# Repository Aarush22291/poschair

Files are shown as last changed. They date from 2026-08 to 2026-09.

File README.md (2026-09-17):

# 🪑 PosChair v1.3 — AI-Powered Active Posture Correction Chair
### Master Technical & Operating Manual

> **Patent Pending · PosChair Technologies Inc.**  
> An active posture correction system powered by real-time computer vision, biomechanical kinematic modeling, and a 6-zone motorized paraspinal backrest attachment.






> **Current readiness:** The software is hardened for prototype evaluation. The powered chair remains an **unoccupied bench prototype** until the [production-readiness hardware gates](docs/production_readiness.md) are completed and independently verified.

---

## 📋 Table of Contents

1. [Executive Summary & Biomechanical Concept](#-1-executive-summary--biomechanical-concept)
2. [How to Run PosChair in 60 Seconds (Beginner Guide)](#-2-how-to-run-poschair-in-60-seconds-beginner-guide)
3. [Full Application Dashboard & UI Guide](#-3-full-application-dashboard--ui-guide)
4. [Biomechanical Kinematics & Math Formulas](#-4-biomechanical-kinematics--math-formulas)
5. [2×3 Paraspinal Actuator Matrix Architecture](#-5-23-paraspinal-actuator-matrix-architecture)
6. [Hardware Wiring & Assembly Reference](#-6-hardware-wiring--assembly-reference)
7. [NimBLE Bluetooth Low Energy Protocol (v1.3)](#-7-nimble-bluetooth-low-energy-protocol-v13)
8. [Software Development & Build Commands](#-8-software-development--build-commands)
9. [Complete Repository Directory Map](#-9-complete-repository-directory-map)
10. [Troubleshooting & Frequently Asked Questions (FAQ)](#-10-troubleshooting--frequently-asked-questions-faq)
11. [Safety & Watchdog Failsafe Systems](#-11-safety--watchdog-failsafe-systems)
12. [Patent Reservation & License Notice](#-12-patent-reservation--license-notice)

---

## 💡 1. Executive Summary & Biomechanical Concept

### The Problem with Ergonomic Chairs
Traditional ergonomic office chairs are **passive support structures**. They only assist your lumbar spine if you maintain ideal posture voluntarily. As fatigue sets in during desk work, users inevitably slump forward (thoracic kyphosis), lean to one side (asymmetric spinal loading), or crane their neck toward the monitor ("tech neck"). Passive chairs do nothing to detect or correct these biomechanical failures.

### The PosChair Active Solution
PosChair is a **vision-guided ergonomic chair prototype**:
* **Camera Vision Eye:** Tracks 33 3D body landmarks using MediaPipe Pose executing inside client-side WebAssembly (WASM). No video or coordinate data is uploaded by the vision pipeline.
* **Kinematic Posture Engine:** Calculates spine forward deviation, lateral roll tilt, and neck inclination angle relative to a personalized 5-second baseline pose.
* **Motorized Actuation Matrix:** A 2×3 grid of 6 motorized worm-rack actuators provides up to **55mm** of configured prototype travel. Occupied operation requires the independent limits, force controls, and emergency stop listed in the hardware safety gate.

```text
+-----------------------------------------------------------------------------------+
|                           POSCHAIR VISION-GUIDED PROTOTYPE                        |
|                                                                                   |
|  [ User sitting ] ---> [ Browser Webcam ] ---> [ MediaPipe Pose WASM (33 Points) ]|
|          ^                                                   |                    |
|          |                                                   v                    |
|  [ 2x3 Motor Support ] <--- [ ESP32 & H-Bridges ] <--- [ NimBLE BLE (8 Bytes) ]   |
+-----------------------------------------------------------------------------------+
```

---

## ⚡ 2. How to Run PosChair in 60 Seconds (Beginner Guide)

You can run PosChair **with or without physical hardware connected**. If you don't have the hardware built yet, PosChair includes a **Live Hardware Simulator** directly on the camera screen so you can test all posture features immediately!

### System Requirements
* **Operating System:** Windows 10/11, macOS, or Linux.
* **Browser:** **Google Chrome** or **Microsoft Edge** (Required for Web Bluetooth API). Safari and Firefox do NOT support Web Bluetooth.
* **Webcam:** Any standard USB or built-in webcam ($640 \times 480$ or higher).
* **Node.js:** Node.js **24.x LTS** (pinned in CI).
* **Python:** Python **3.12.x** (pinned in CI for backend checks).

---

### Method A: Double-Click Desktop Launcher (Easiest — No Code Required)

1. Download or clone this repository to your computer.
2. Open the project folder in Windows Explorer.
3. Double-click the file:
   ```text
   run-poschair.bat
   ```
4. The launcher will install missing packages automatically, start the server, and open **`http://localhost:5173`** in your default web browser!

---

### Method B: Manual Command Line Launch

Open Terminal or Command Prompt in the repository folder:

```bash
# 1. Enter the frontend application directory
cd app/frontend

# 2. Install dependencies (only required on first run)
npm install

# 3. Launch the development server
npm run dev
```

Open **`http://localhost:5173`** in Google Chrome or Microsoft Edge.

---

### Method C: Full-Stack Docker Container Launch

For developers running the full backend stack (React Frontend + FastAPI Backend + PostgreSQL Database):

```bash
cd app
docker-compose up --build
```

Open **`http://localhost:5173`** in Chrome or Edge.

---

## 🎮 3. Full Application Dashboard & UI Guide

When you open the application at `http://localhost:5173`, the dashboard provides real-time biomechanical feedback:

```text
+----------------------------------------------------------------------------------+
|  POSCHAIR v1.3               [ Connect Chair ]  [ Stop Camera ]  [ Mode: Office ]|
+----------------------------------------------------------------------------------+
|                                        |                                         |
|   LIVE POSTURE VIDEO FEED              |   CHAIR HARDWARE VISUALIZER             |
|   +--------------------------------+   |   +---------------------------------+   |
|   | [Score: 85 (Good)]  [HARDWARE] |   |   |  Upper-Left:  18mm  [====---]  |   |
|   |                     [DIAGRAM ] |   |   |  Upper-Right: 18mm  [====---]  |   |
|   |   (33 Yellow Joint Dots &      |   |   |  Mid-Left:    45mm  [========]  |   |
|   |    Green/Red Spine Line)       |   |   |  Mid-Right:   45mm  [========]  |   |
|   |                                |   |   |  Lower-Left:  32mm  [======--]  |   |
|   | [Spine:+8.4°] [Lat:-1.2°]      |   |   |  Lower-Right: 32mm  [======--]  |   |
|   +--------------------------------+   |   +---------------------------------+   |
|                                        |                                         |
|   [ Calibrate Baseline ] [ Session Clock ] |   INTEGRATION SETTINGS                  |
|   Spine Velocity: +2.1 deg/s           |   [ Local CV Only ]  [ Active BLE Loop ] |
|                                        |                                         |
|   ANALYTICS TREND CHART                |   MANUAL POSITION OVERRIDE              |
|   [==================================] |   Module 1 Position: [-------o----] 35mm|
+----------------------------------------------------------------------------------+
```

### Detailed Feature Breakdown

#### 1. Live Posture Video Panel (`CameraView.tsx`)
* **Full Body Skeleton Overlay:** Draws all 33 pose landmarks as prominent **yellow dots** (matching the physical reference design).
* **Posture-Aware Spine Line:** Highlights the line from Hip Midpoint → Shoulder Midpoint → Ear Midpoint:
  * **Green:** Excellent alignment ($\text{Score} \ge 75$)
  * **Yellow/Amber:** Minor posture deviation ($\text{Score } 50\text{--}74$)
  * **Red:** Severe posture slump ($\text{Score} < 50$)
* **Live Bottom Metric Pills:**
  * **`Spine (°)`:** Angle of torso forward lean relative to vertical (e.g. `+12.4°`).
  * **`Lateral (°)`:** Shoulder roll tilt angle left/right (e.g. `-4.2°`).
  * **`Neck (°)`:** Ear-to-shoulder inclination angle (Tech Neck proxy, e.g. `+14.7°`).
  * **`Confidence (%)`:** Pose tracking confidence score (e.g. `98% conf`).

#### 2. Live Hardware Motor Simulator Widget (Top-Right of Video)
* **Vibrant Blue Oval Chair Backrest Diagram (`front side of chair`):** Represents the physical backrest layout.
* **6 Actuator Nodes (`UL`, `UR`, `ML`, `MR`, `LL`, `LR`):**
  * **Bright Yellow (`0mm`):** Motor is idle/resting.
  * **Glowing Red + Pulse (`1–55mm`):** The prototype is commanding actuator extension.
  * **Real-time Readout:** Displays exact millimeter extension inside each circle.

#### 3. 5-Second Baseline Calibration (`CalibrationModal.tsx`)
* Clicking **"Calibrate Baseline"** prompts you to sit in your natural, healthy upright pose for 5 seconds.
* The system samples high-confidence frames ($\text{confidence} \ge 0.65$) and calculates your personalized baseline values:
  * $\text{spineAngle0}$, $\text{lateralAngle0}$, $\text{neckAngle0}$, $\text{shoulderWidth}$, $\text{torsoLength}$.
* All posture deviations are measured **relative to your baseline**, ensuring accurate operation regardless of camera height or user body dimensions.

#### 4. Posture Modes (`ModeSelector.tsx`)
* **Office Mode ($1.0\times$):** Standard balanced posture correction.
* **Gaming Mode ($1.2\times$):** Higher aggressiveness for forward-slouched gaming sessions.
* **Study Mode ($0.85\times$):** Moderated support for reading/writing.
* **Relax Mode ($0.5\times$):** Gentle baseline support.

#### 5. Integration Settings
* **Local CV Only:** Runs full camera tracking, biomechanical analysis, and live UI motor simulation without transmitting Bluetooth packets.
* **Active BLE Loop:** Continuously streams 8-byte command packets to the physical ESP32 chair controller over Bluetooth.

---

## 🧮 4. Biomechanical Kinematics & Math Formulas

### 1. Scale & Distance Invariance
To ensure posture calculations remain identical whether you sit close to or far from your webcam, all vector distances are scaled by your baseline **Torso Length** and **Shoulder Width**:

$$\text{torsoScale} = \frac{\text{CurrentTorsoLength}}{\text{BaselineTorsoLength}}$$

$$\text{forwardHeadRatio} = \frac{\text{MidEar}_x - \text{MidShoulder}_x}{\text{ShoulderWidth} \times \text{torsoScale}}$$

### 2. Exponential Moving Average (EMA) Temporal Filter
To eliminate camera frame jitter while retaining real-time responsiveness, all raw angular outputs pass through an EMA filter ($\alpha = 0.35$):

$$S_t = \alpha \cdot X_t + (1 - \alpha) \cdot S_{t-1}$$

### 3. Neck Inclination Angle (Tech Neck Proxy)
Calculated using the ear-to-shoulder inclination vector averaged across left and right sides:

$$\theta_{\text{neck}} = \text{atan2}(|\text{Ear}_x - \text{Shoulder}_x|, |\text{Ear}_y - \text{Shoulder}_y|) \times \left(\frac{180}{\pi}\right)$$

### 4. 3-Component Posture Score Formula
$$\text{Score} = \max\left(0, \min\left(100, 100 - P_{\text{spine}} - P_{\text{lateral}} - P_{\text{neck}}\right)\right)$$

Where:
* $P_{\text{spine}} = \min\left(40, \frac{|\Delta \text{Spine}|}{20^\circ} \times 40\right)$
* $P_{\text{lateral}} = \min\left(30, \frac{|\Delta \text{Lateral}|}{10^\circ} \times 30\right)$
* $P_{\text{neck}} = \min\left(30, \frac{|\Delta \text{Neck}|}{25^\circ} \times 30\right)$

### 5. Velocity Bonus & Differential Lateral Split
* **Velocity Bonus:** Adds up to $+15\text{mm}$ extra motor extension if the user slumps rapidly ($\text{SpineVelocity} > 3^\circ/\text{s}$).
* **Differential Lateral Split:**
  * Leaning **RIGHT** ($\Delta \text{Lateral} > +2^\circ$) $\rightarrow$ Adds extension bonus exclusively to **Right Column** (`UR`, `MR`, `LR`).
  * Leaning **LEFT** ($\Delta \text{Lateral} < -2^\circ$) $\rightarrow$ Adds extension bonus exclusively to **Left Column** (`UL`, `ML`, `LL`).

---

## 🪑 5. 2×3 Paraspinal Actuator Matrix Architecture

The physical chair attachment features 6 worm-rack actuators arranged in a **2×3 grid**:

```text
        LEFT COLUMN          RIGHT COLUMN
ROW 1:  [ M0 - UL ]         [ M1 - UR ]      Upper Thoracic / Shoulder
ROW 2:  [ M2 - ML ]         [ M3 - MR ]      Mid Lumbar
ROW 3:  [ M4 - LL ]         [ M5 - LR ]      Lower Lumbar / Pelvis
```

* **Center Spinal Channel:** A 2cm open vertical gap down the center ensures pads press into the **paraspinal muscle lines**, never pressing directly on spinal vertebrae.
* **Flex Strips:** Actuators drive pre-curved **65Mn spring steel strips** that provide 20mm of natural curvature at rest and flex up to 55mm total extension under load.

---

## 🔌 6. Hardware Wiring & Assembly Reference

### Bill of Materials (BOM)
| Item | Qty | Description / Part Notes |
|---|---:|---|
| **ESP32 DevKit V1** | 1 | 38-pin microcontroller (`ESP32 Dev Module`) |
| **BTS7960 Motor Driver** | 6 | High-current H-Bridge drivers (1 per motor) |
| **DC Geared Motors** | 6 | High-torque 12V DC geared motors with worm-racks |
| **12V Motor Battery/Power**| 1 | Dedicated 12V 10A+ motor power supply |
| **120kΩ Resistor** | 1 | Battery divider high-side resistor |
| **27kΩ Resistor** | 1 | Battery divider low-side resistor |
| **100nF Capacitor** | 1 | ADC midpoint filtering capacitor |
| **Inline Fuse** | 1 | Sized for the motor supply and wiring |
| **Latching Emergency Stop** | 1 | Required before any occupied-chair testing |
| **Common Ground Bus** | 1 | Required common ground line |

---

### ESP32 Pin Connection Table

| Module Index | Body Position | BTS7960 RPWM | BTS7960 LPWM | Shared Enable | Motor Output |
|---|---|---|---|---|---|
| **M0** | Upper-Left (UL) | ESP32 `GPIO25` | ESP32 `GPIO26` | `GPIO5` | Motor 0 `M+`/`M-` |
| **M1** | Upper-Right (UR) | ESP32 `GPIO27` | ESP32 `GPIO16` | `GPIO5` | Motor 1 `M+`/`M-` |
| **M2** | Mid-Left (ML) | ESP32 `GPIO14` | ESP32 `GPIO13` | `GPIO5` | Motor 2 `M+`/`M-` |
| **M3** | Mid-Right (MR) | ESP32 `GPIO17` | ESP32 `GPIO18` | `GPIO5` | Motor 3 `M+`/`M-` |
| **M4** | Lower-Left (LL) | ESP32 `GPIO21` | ESP32 `GPIO22` | `GPIO5` | Motor 4 `M+`/`M-` |
| **M5** | Lower-Right (LR) | ESP32 `GPIO23` | ESP32 `GPIO19` | `GPIO5` | Motor 5 `M+`/`M-` |

---

### BTS7960 Driver Connections (Per Driver Board)

```text
  +--------------------------------------------------------------------+
  |                        BTS7960 H-BRIDGE DRIVER                     |
  |                                                                    |
  |   RPWM ----> Assigned ESP32 RPWM GPIO (Extends motor)             |
  |   LPWM ----> Assigned ESP32 LPWM GPIO (Retracts motor)            |
  |   R_EN ----> ESP32 GPIO5 (Shared Driver Enable)                   |
  |   L_EN ----> ESP32 GPIO5 (Shared Driver Enable)                   |
  |   VCC  ----> ESP32 3.3V (Logic Power)                             |
  |   GND  ----> Common Ground Bus                                    |
  |   B+   ----> 12V Motor Battery Positive                           |
  |   B-   ----> Common Ground Bus (12V Battery Negative)             |
  |   M+   ----> DC Geared Motor Terminal 1                           |
  |   M-   ----> DC Geared Motor Terminal 2                           |
  +--------------------------------------------------------------------+
```

> ⚡ **CRITICAL POWER RULES:**  
> 1. **Common Ground:** ESP32 GND, BTS7960 GND, and 12V Battery Negative MUST be connected to a single common ground bus.  
> 2. **Separate Motor Rail:** Never power DC motors directly from the ESP32 board or USB cable.  
> 3. **Motor Polarity:** If a motor retracts when it should extend, swap its `M+` and `M-` wires on the BTS7960 driver terminal.

---

### Battery Voltage Sensing Circuit
Use a 120kΩ/27kΩ divider to keep the ESP32 ADC input below 3.3V throughout the supported 0-15V motor-supply range. Add a 100nF capacitor from the ADC midpoint to ground:

```text
12V Battery Positive ---- [ 120kΩ R1 ] ----+---- [ 27kΩ R2 ] ---- Ground Bus
                                            |
                                      ESP32 GPIO34
                                            |
                                         [100nF]
                                            |
                                      Ground Bus
```

> **Do not use the former 100kΩ/100kΩ divider.** A 12V input would place about 6V at the midpoint, above the ESP32 ADC pin limit and capable of damaging the controller.

---

## 📡 7. NimBLE Bluetooth Low Energy Protocol (v1.3)

* **Device Local Name:** `POSCHAIR_001`
* **Service UUID:** `a1b2c3d4-0001-4b5c-8d6e-1f2a3b4c5d6e`
* **Command Characteristic:** `a1b2c3d4-0002-4b5c-8d6e-1f2a3b4c5d6e` (Write Without Response)
* **Status Characteristic:** `a1b2c3d4-0003-4b5c-8d6e-1f2a3b4c5d6e` (Notify)

### 8-Byte Command Packet Map (App → ESP32)

| Byte | Field | Type | Value Range | Description |
|---|---|---|---|---|
| `0` | Header | `uint8_t` | `0xA5` | Fixed packet start byte |
| `1` | UL Position | `uint8_t` | `0–55` | Target extension in millimeters |
| `2` | UR Position | `uint8_t` | `0–55` | Target extension in millimeters |
| `3` | ML Position | `uint8_t` | `0–55` | Target extension in millimeters |
| `4` | MR Position | `uint8_t` | `0–55` | Target extension in millimeters |
| `5` | LL Position | `uint8_t` | `0–55` | Target extension in millimeters |
| `6` | LR Position | `uint8_t` | `0–55` | Target extension in millimeters |
| `7` | Checksum | `uint8_t` | Byte | XOR verification of bytes 0–6 |

$$\text{Checksum} = B_0 \oplus B_1 \oplus B_2 \oplus B_3 \oplus B_4 \oplus B_5 \oplus B_6$$

### Command Packet Debug Vectors

```text
All Motors Home (0mm):           A5 00 00 00 00 00 00 A5
Mid Lumbar Actuation (32mm):     A5 00 00 20 20 00 00 A5
Right Column Full Out (55mm):    A5 00 37 00 37 00 37 92
Full Matrix Out (55mm):          A5 37 37 37 37 37 37 A5
```

---

## 8. Software Development & Build Commands

### Frontend Development (React + Vite + TypeScript)
```bash
cd app/frontend
npm install
npm run dev      # Start Vite dev server on http://localhost:5173
npm run lint     # ESLint quality gate (0 warnings allowed)
npm run test     # Vitest unit tests
npm run build    # Production build check (tsc && vite build)
```

### Marketing Website Development (Next.js)
```bash
cd website
npm install
npm run dev      # Start Next.js dev server on http://localhost:3000
npm run lint     # ESLint quality gate (0 warnings allowed)
npm run build    # Production static page build (next build)
```

### Backend Development (FastAPI + SQLAlchemy)
```bash
cd app/backend
python -m pip install -r requirements-dev.txt
python -m ruff check src tests
python -m ruff format --check tests
DATABASE_URL=sqlite:///./test_poschair.db python -m pytest -q
```

### Developer Quick-Check (Pre-PR)
```bash
# Frontend
cd /home/runner/work/poschair/poschair/app/frontend && npm run lint && npm run test && npm run build

# Website
cd /home/runner/work/poschair/poschair/website && npm run lint && npm run build

# Backend
cd /home/runner/work/poschair/poschair/app/backend && python -m ruff check src tests && python -m ruff format --check tests && DATABASE_URL=sqlite:///./test_poschair.db python -m pytest -q
```

### Firmware Compilation (Arduino IDE 2.x)
1. Open `firmware/poschair_firmware/poschair_firmware.ino` in Arduino IDE.
2. Install Library: **NimBLE-Arduino** (via Library Manager).
3. Board Selection: **`ESP32 Dev Module`**.
4. Settings: CPU Frequency `240MHz`, Flash Size `4MB`.
5. Upload Speed: `921600`.

---

## 📁 9. Complete Repository Directory Map

```text
poschair_final/
├── run-poschair.bat            # 1-Click Desktop Launcher for Windows
├── README.md                   # Master Technical & Operating Manual
├── LICENSE                     # Proprietary & Patent-Pending License
├── app/
│   ├── frontend/               # Dashboard App (React, Vite, Web Bluetooth, MediaPipe)
│   │   ├── src/
│   │   │   ├── App.tsx         # Core App component, state management, retry loader
│   │   │   ├── poseDetector.ts # MediaPipe WASM detector loader & DrawingUtils wrapper
│   │   │   ├── postureAnalyzer.ts # EMA filter, neck inclination, posture score math
│   │   │   ├── decisionEngine.ts  # Paraspinal matrix position mapping & velocity bonus
│   │   │   ├── bleManager.ts      # Web Bluetooth manager & 8-byte XOR packet encoder
│   │   │   ├── apiClient.ts       # Backend REST client + packaged local storage
│   │   │   └── components/
│   │   │       ├── CameraView.tsx # Video feed, 33-landmark skeleton, hardware diagram
│   │   │       ├── SpineVisualizer.tsx # 2x3 grid actuator dual progress bars
│   │   │       ├── CalibrationModal.tsx # 5-second natural pose baseline capture
│   │   │       ├── AnalyticsDashboard.tsx # Recharts posture trend line & daily bar charts
│   │   │       ├── BLEStatusBar.tsx # Bluetooth diagnostics bar
│   │   │       ├── ModeSelector.tsx # Office/Gaming/Study/Relax mode selector
│   │   │       └── LateralLeanAlert.tsx # Real-time side-lean alert banner
│   ├── backend/                # FastAPI Python Backend
│   │   ├── src/
│   │   │   ├── main.py         # FastAPI router & CORS middleware
│   │   │   ├── models.py       # SQLAlchemy User, Calibration, Session models
│   │   │   ├── database.py     # SQLite/PostgreSQL connection
│   │   │   └── routes/         # Profile, Calibration, Session REST routes
│   └── docker-compose.yml      # Docker container stack configuration
├── firmware/
│   ├── poschair_firmware/      # Main ESP32 BLE peripheral & motor controller firmware
│   │   ├── poschair_firmware.ino
│   │   ├── config.h            # Pinouts, MAX_POSITION_MM (55mm), watchdog constants
│   │   ├── motor_controller.h  # Timed open-loop position calculation engine
│   │   └── motor_controller.cpp
│   └── test/                   # Standalone direction, cycle, and battery bench-test sketch
├── docs/
│   ├── hardware_wiring.md      # Pinout schematics, power wiring & assembly checklist
│   ├── protocol.md             # Complete BLE binary protocol specification
│   ├── production_readiness.md # Human-use gates, evidence, and funding milestones
│   └── system_working_diagram.md # End-to-end Mermaid system flow diagrams
└── website/                    # Next.js Marketing & Interactive Documentation Site
    ├── src/
    │   ├── pages/
    │   │   ├── index.tsx       # Homepage with live telemetry simulator & specs table
    │   │   └── docs.tsx        # Interactive hover system guide & documentation hub
    │   └── components/
    │       ├── Hero.tsx        # Interactive 2x3 hardware telemetry simulator console
    │       ├── InteractiveDocs.tsx # 6-pillar hover-to-explain interactive explorer
    │       ├── Features.tsx    # Technical architecture & engineering cards
    │       ├── HowItWorks.tsx  # Vision-to-actuation pipeline steps
    │       ├── Nav.tsx         # Navbar with v1.3 tag & Docs link
    │       └── Footer.tsx      # Footer with patent notice
```

---

## ❓ 10. Troubleshooting & Frequently Asked Questions (FAQ)

### Q1: Why does the camera feed say "Camera / Model Error"?
* **Cause:** Camera permissions are blocked or another app (Zoom, Teams, Discord) is using your webcam.
* **Fix:** Close other video applications, click the lock icon next to `http://localhost:5173` in your browser address bar, set Camera to **Allow**, and refresh the page.

### Q2: Why does "Connect Chair" fail to find the Bluetooth device?
* **Cause 1:** You are using Firefox or Safari.  
  * **Fix:** Use **Google Chrome** or **Microsoft Edge**.
* **Cause 2:** The ESP32 is not powered on or BLE is already connected to your phone.  
  * **Fix:** Power the ESP32, verify `POSCHAIR_001` appears in Bluetooth settings, and restart the ESP32.

### Q3: What if one motor moves backward during testing?
* **Cause:** DC motor wires are reversed on the BTS7960 output.
* **Fix:** Do not edit software. Swap the `M+` and `M-` wires for that module directly on the BTS7960 terminal block.

### Q4: Can I run PosChair without building the physical chair?
* **Yes!** Switch Integration Settings to **Local CV Only**. The full camera skeleton, biomechanical score, and live top-right **Chair Hardware Simulator Diagram** will operate seamlessly in your browser.

---

## 🛡️ 11. Safety & Watchdog Failsafe Systems

1. **Best-Effort Bluetooth Watchdog:** If valid command packets cease for more than 2 seconds, the firmware requests retraction to `0mm`. This is not a safety-rated control and cannot prove that an actuator physically moved.
2. **Bench-Only Startup Homing:** Every boot runs each motor inward for a fixed time and then sets its software estimate to `0mm`. Until independent limit switches or encoders are fitted, this can stall a motor and does not guarantee physical home.
3. **Command Clamping:** Firmware clamps requested travel to `MAX_POSITION_MM = 55mm`. Reported positions are open-loop estimates, not measurements.
4. **Hardware Safety Gate:** Do not test the chair with a person until it has a normally-closed latching emergency stop, independent travel limits, current/force monitoring, mechanical stops, protected motor channels, and verified pressure/force limits. See [Hardware Wiring](docs/hardware_wiring.md#human-use-hardware-gate).

Cutting motor power is not guaranteed to retract or release a geared actuator. The emergency stop must be designed around the measured behavior of the final mechanism.

---

## ⚖️ 12. Patent Reservation & License Notice

**Copyright (c) 2026 PosChair Technologies Inc. All Rights Reserved. Patent Pending.**

This software, firmware, 2×3 paraspinal matrix hardware designs, kinematic biomechanical algorithms, and documentation are subject to pending patent applications. 

Commercial manufacturing, distribution, marketing, or licensing without explicit prior written authorization from **PosChair Technologies Inc.** is strictly prohibited. Personal, non-commercial evaluation and academic research are permitted under the terms of the [LICENSE](LICENSE).

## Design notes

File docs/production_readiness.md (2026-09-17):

# PosChair Production Readiness

## Current Classification

PosChair is a software-hardened, unoccupied bench prototype. It is not yet ready
for powered testing against a person, commercial manufacture, or unsupervised
operation. The software watchdog and open-loop position estimate are useful
fallbacks, but neither is a safety-rated control.

## Implemented Software Controls

- Actuator output starts disabled and requires connection, calibration, and an explicit bench-test confirmation.
- Missing 3D pose data or low confidence commands all targets to 0mm.
- BLE writes are serialized with a latest-command-wins queue.
- Firmware clamps commands to 0-55mm and requests retraction after two seconds without a valid packet.
- Mid-motion target changes update the open-loop position estimate before reversing or changing duration.
- Battery telemetry uses a 120k/27k divider sized for up to 15V input, plus ADC filtering and calibration support.
- Desktop builds persist profiles, calibration, and sessions locally without requiring a separate backend.
- API payloads are bounded and validated, timestamps are timezone-aware, and invalid user references are rejected.
- CI lints, tests, builds, and compiles the frontend, backend, website, and ESP32 firmware.

## Blocking Hardware Gates

All items below are required before occupied powered testing:

1. Normally-closed, latching emergency stop that removes motor power independently of software.
2. Independent retract and extend limit sensing on every actuator.
3. Closed-loop position feedback from encoders or equivalent sensors.
4. Current, load, or force monitoring with an independent cutoff path.
5. Mechanical stops rated for worst-case stall load and foreseeable misuse.
6. Per-channel electrical protection sized from measured motor stall current.
7. Measured and documented pad-force and contact-pressure limits across the full travel range.
8. Verified behavior for jams, disconnected sensors, reversed wiring, BLE loss, application failure, and controller reset.

## Verification Evidence Needed

- Electrical schematic, wiring review, fuse calculations, and measured current data.
- Mechanical drawings, material specifications, load calculations, and cycle-life results.
- Calibration procedure for actuator speed, position feedback, force sensing, and battery voltage.
- Traceable test cases with pass/fail records for every safety requirement and fault condition.
- A controlled pilot plan beginning with instrumented, unoccupied tests before any supervised human evaluation.
- Independent legal, regulatory, clinical, and intellectual-property review before public safety or medical claims.

## Funding Milestones

1. Build one instrumented actuator channel with limits, encoder feedback, force sensing, and hardware cutoff.
2. Validate the channel across expected loads, jams, power loss, and repeated cycles.
3. Replicate the verified channel six times and validate simultaneous operation and power integrity.
4. Integrate the emergency stop and system-level fault handling, then complete an independent design review.
5. Only after the preceding gates pass, define a supervised human-factors study with qualified advisors.

This sequence turns the current prototype into a fundable engineering program
without presenting software fallbacks as proof of physical safety.

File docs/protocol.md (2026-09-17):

# PosChair BLE Protocol Specification (V3)

This document defines the binary BLE protocol between the browser app and the ESP32 DevKit V1 motor controller.

## Device Information

- **BLE Device Local Name:** `POSCHAIR_001`
- **Service UUID:** `a1b2c3d4-0001-4b5c-8d6e-1f2a3b4c5d6e`
- **Command Characteristic:** `a1b2c3d4-0002-4b5c-8d6e-1f2a3b4c5d6e`
- **Status Characteristic:** `a1b2c3d4-0003-4b5c-8d6e-1f2a3b4c5d6e`

## Module Order

```text
0 = Upper-Left   (UL)
1 = Upper-Right  (UR)
2 = Mid-Left     (ML)
3 = Mid-Right    (MR)
4 = Lower-Left   (LL)
5 = Lower-Right  (LR)
```

All command and status arrays use this exact order.

## Command Packet

App to ESP32, 8 bytes, write without response. Position units are millimeters.

| Byte | Field | Type | Description |
|---|---|---|---|
| 0 | Header | `uint8_t` | Constant `0xA5` |
| 1 | UL position | `uint8_t` | 0-55mm |
| 2 | UR position | `uint8_t` | 0-55mm |
| 3 | ML position | `uint8_t` | 0-55mm |
| 4 | MR position | `uint8_t` | 0-55mm |
| 5 | LL position | `uint8_t` | 0-55mm |
| 6 | LR position | `uint8_t` | 0-55mm |
| 7 | Checksum | `uint8_t` | XOR of bytes 0-6 |

```text
checksum = B0 ^ B1 ^ B2 ^ B3 ^ B4 ^ B5 ^ B6
```

## Status Packet

ESP32 to app, 10 bytes, notify about once per second.

| Byte | Field | Type | Description |
|---|---|---|---|
| 0 | Header | `uint8_t` | Constant `0x5A` |
| 1 | Flags | `uint8_t` | bit0=ok, bit1=failsafe, bit2=homed, bit3=any motor moving |
| 2 | Battery voltage MSB | `uint8_t` | Big-endian millivolts |
| 3 | Battery voltage LSB | `uint8_t` | Big-endian millivolts |
| 4 | UL estimated position | `uint8_t` | 0-55mm |
| 5 | UR estimated position | `uint8_t` | 0-55mm |
| 6 | ML estimated position | `uint8_t` | 0-55mm |
| 7 | MR estimated position | `uint8_t` | 0-55mm |
| 8 | LL estimated position | `uint8_t` | 0-55mm |
| 9 | LR estimated position | `uint8_t` | 0-55mm |

## Test Packets

```text
All retracted:         A5 00 00 00 00 00 00 A5
ML+MR to 50mm:         A5 00 00 32 32 00 00 A5
Full left column out:  A5 37 00 37 00 37 00 92
All fully extended:    A5 37 37 37 37 37 37 A5
```

Positions reported in status packets are open-loop time estimates. They are
not encoder measurements and must not be treated as verified physical travel.

## Failsafe

If no valid command packet arrives for more than `FAILSAFE_TIMEOUT_MS` (2000ms), the ESP32 sets the failsafe flag and commands all modules back to 0mm.

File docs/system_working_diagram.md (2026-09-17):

# PosChair V3 System Working Diagram

This document shows the full PosChair V3 system from every user, sensor, software, BLE, firmware, driver, motor, actuator, and feedback input to every output.

## 1. End-to-End System Flow

```mermaid
flowchart LR
  User["User sitting on chair"]
  Camera["Browser camera input"]
  Light["Lighting / camera angle"]
  Browser["Chrome or Edge dashboard"]
  Pose["MediaPipe Pose WASM"]
  Analyzer["Posture Analyzer"]
  Decision["V3 Decision Engine"]
  BLEClient["Web Bluetooth Manager"]
  BLEAir["BLE radio link"]
  ESP32["ESP32 DevKit V1 firmware"]
  MotorCtrl["MotorController timed-position model"]
  Drivers["6x BTS7960 H-bridge drivers"]
  Motors["6x DC geared motors"]
  WormRack["6x worm-rack actuators"]
  FoamPads["6x foam pads"]
  Back["User paraspinal muscles"]
  Status["BLE status notify"]
  UI["Dashboard UI"]
  Backend["FastAPI backend"]
  DB["PostgreSQL database"]

  User --> Camera
  Light --> Camera
  Camera --> Browser
  Browser --> Pose
  Pose --> Analyzer
  Analyzer --> Decision
  Decision --> BLEClient
  BLEClient --> BLEAir
  BLEAir --> ESP32
  ESP32 --> MotorCtrl
  MotorCtrl --> Drivers
  Drivers --> Motors
  Motors --> WormRack
  WormRack --> FoamPads
  FoamPads --> Back
  Back --> User

  ESP32 --> Status
  Status --> BLEAir
  BLEAir --> BLEClient
  BLEClient --> UI
  Analyzer --> UI
  Decision --> UI
  UI --> Backend
  Backend --> DB
  DB --> Backend
  Backend --> UI
```

## 1A. Physical Wiring Connection Diagram

```mermaid
flowchart LR
  ESP["ESP32 DevKit V1"]
  GND["Common ground bus"]
  V33["ESP32 3.3V"]
  EN["GPIO5 shared enable"]
  ADC["GPIO34 battery ADC"]
  BATP["12V battery positive"]
  BATN["12V battery negative"]
  Fuse["Fuse / switch"]
  Divider["120k / 27k divider + 100nF filter"]

  subgraph Drivers["BTS7960 drivers"]
    D0["M0 UL driver"]
    D1["M1 UR driver"]
    D2["M2 ML driver"]
    D3["M3 MR driver"]
    D4["M4 LL driver"]
    D5["M5 LR driver"]
  end

  subgraph Motors["DC motors and actuators"]
    M0["M0 upper-left motor"]
    M1["M1 upper-right motor"]
    M2["M2 mid-left motor"]
    M3["M3 mid-right motor"]
    M4["M4 lower-left motor"]
    M5["M5 lower-right motor"]
  end

  ESP -->|"GPIO25 RPWM, GPIO26 LPWM"| D0
  ESP -->|"GPIO27 RPWM, GPIO16 LPWM"| D1
  ESP -->|"GPIO14 RPWM, GPIO13 LPWM"| D2
  ESP -->|"GPIO17 RPWM, GPIO18 LPWM"| D3
  ESP -->|"GPIO21 RPWM, GPIO22 LPWM"| D4
  ESP -->|"GPIO23 RPWM, GPIO19 LPWM"| D5

  EN -->|"R_EN + L_EN"| D0
  EN -->|"R_EN + L_EN"| D1
  EN -->|"R_EN + L_EN"| D2
  EN -->|"R_EN + L_EN"| D3
  EN -->|"R_EN + L_EN"| D4
  EN -->|"R_EN + L_EN"| D5

  V33 -->|"VCC logic"| D0
  V33 -->|"VCC logic"| D1
  V33 -->|"VCC logic"| D2
  V33 -->|"VCC logic"| D3
  V33 -->|"VCC logic"| D4
  V33 -->|"VCC logic"| D5

  BATP --> Fuse
  Fuse -->|"B+"| D0
  Fuse -->|"B+"| D1
  Fuse -->|"B+"| D2
  Fuse -->|"B+"| D3
  Fuse -->|"B+"| D4
  Fuse -->|"B+"| D5

  BATN --> GND
  ESP -->|"GND"| GND
  GND -->|"GND and B-"| D0
  GND -->|"GND and B-"| D1
  GND -->|"GND and B-"| D2
  GND -->|"GND and B-"| D3
  GND -->|"GND and B-"| D4
  GND -->|"GND and B-"| D5

  D0 -->|"M+ / M-"| M0
  D1 -->|"M+ / M-"| M1
  D2 -->|"M+ / M-"| M2
  D3 -->|"M+ / M-"| M3
  D4 -->|"M+ / M-"| M4
  D5 -->|"M+ / M-"| M5

  BATP --> Divider
  GND --> Divider
  Divider --> ADC
```

## 1B. One Driver Wiring Template

```mermaid
flowchart TB
  ESP["ESP32 DevKit"]
  Driver["One BTS7960 driver"]
  Motor["One DC geared motor"]
  Battery["12V motor supply"]
  Ground["Common ground"]

  ESP -->|"Assigned RPWM GPIO"| Driver
  ESP -->|"Assigned LPWM GPIO"| Driver
  ESP -->|"GPIO5 to R_EN"| Driver
  ESP -->|"GPIO5 to L_EN"| Driver
  ESP -->|"3.3V to VCC"| Driver
  ESP -->|"GND"| Ground
  Ground -->|"GND and B-"| Driver
  Battery -->|"B+"| Driver
  Driver -->|"M+"| Motor
  Driver -->|"M-"| Motor
```

## 2. Inputs and Outputs

```mermaid
flowchart TB
  subgraph Inputs["Inputs"]
    CameraFrames["Camera frames"]
    UserMode["Mode selection: office / gaming / study / relax"]
    Calibration["Calibration baseline"]
    ManualOverride["Manual position sliders"]
    BLEStatusIn["ESP32 status notifications"]
    BatterySense["Battery voltage divider on GPIO34"]
    MotorSpeedCal["MOTOR_SPEED_MM_PER_MS calibration"]
    PowerOn["Power-on / reset"]
    BLEDisconnect["BLE disconnect or silent packets"]
  end

  subgraph Processing["Processing"]
    PoseDetection["Pose landmark detection"]
    ConfidenceGate["Confidence gate >= 0.65"]
    Geometry["Spine, lateral, head-offset geometry"]
    Velocity["Spine and lateral velocity calculation"]
    PositionMapping["0-55mm target mapping"]
    PacketBuild["8-byte BLE command packet"]
    PacketParse["ESP32 checksum validation"]
    BatteryRead["Battery ADC reading"]
    TimedMotion["Timed motor run duration"]
    Homing["Startup homing to 0mm"]
    Failsafe["2-second BLE failsafe"]
  end

  subgraph Outputs["Outputs"]
    TargetPositions["Target positions: UL UR ML MR LL LR"]
    Dashboard["Live dashboard state"]
    BLEPacket["BLE write without response"]
    PWMOut["RPWM / LPWM PWM output"]
    MotorMotion["Motor extend / retract / brake / coast"]
    PadTravel["Foam pad travel: 0-55mm"]
    SessionLogs["Session analytics logs"]
    RetractionRequest["Request all modules retract to 0mm"]
  end

  CameraFrames --> PoseDetection
  PoseDetection --> ConfidenceGate
  ConfidenceGate --> Geometry
  Geometry --> Velocity
  Velocity --> PositionMapping
  UserMode --> PositionMapping
  Calibration --> Geometry
  ManualOverride --> TargetPositions
  PositionMapping --> TargetPositions
  TargetPositions --> PacketBuild
  PacketBuild --> BLEPacket
  BLEPacket --> PacketParse
  PacketParse --> TimedMotion
  MotorSpeedCal --> TimedMotion
  BatterySense --> BatteryRead
  BatteryRead --> Dashboard
  TimedMotion --> PWMOut
  PWMOut --> MotorMotion
  MotorMotion --> PadTravel
  BLEStatusIn --> Dashboard
  Geometry --> Dashboard
  PositionMapping --> Dashboard
  Dashboard --> SessionLogs
  PowerOn --> Homing
  Homing --> RetractionRequest
  BLEDisconnect --> Failsafe
  Failsafe --> RetractionRequest
```

## 3. Browser App Processing Loop

```mermaid
flowchart TD
  Start["User clicks Enable Tracking"]
  CameraPermission["Request camera permission"]
  LoadModel["Load MediaPipe Pose Landmarker"]
  FrameLoop["requestAnimationFrame loop"]
  Detect["Detect 33 pose landmarks"]
  HasLandmarks{"Landmarks found?"}
  Analyze["Analyze posture geometry"]
  ComputeVelocity["Compute velocity deg/sec"]
  Confidence{"Confidence >= 0.65?"}
  Hold["Hold previous target positions"]
  ComputeTargets["Compute V3 target positions"]
  Hysteresis["Apply 3-unit hysteresis"]
  UpdateUI["Update score, confidence, velocity, grid UI"]
  SendAllowed{"BLE connected and Active BLE Loop?"}
  Throttle{"100ms send interval elapsed?"}
  SendBLE["Send 8-byte position packet"]
  LogScore{"1s score log interval?"}
  SaveHistory["Append score to session history"]
  NextFrame["Next animation frame"]

  Start --> CameraPermission
  CameraPermission --> LoadModel
  LoadModel --> FrameLoop
  FrameLoop --> Detect
  Detect --> HasLandmarks
  HasLandmarks -- "No" --> NextFrame
  HasLandmarks -- "Yes" --> Analyze
  Analyze --> ComputeVelocity
  ComputeVelocity --> Confidence
  Confidence -- "No" --> Hold
  Confidence -- "Yes" --> ComputeTargets
  ComputeTargets --> Hysteresis
  Hold --> UpdateUI
  Hysteresis --> UpdateUI
  UpdateUI --> SendAllowed
  SendAllowed -- "No" --> LogScore
  SendAllowed -- "Yes" --> Throttle
  Throttle -- "No" --> LogScore
  Throttle -- "Yes" --> SendBLE
  SendBLE --> LogScore
  LogScore -- "Yes" --> SaveHistory
  LogScore -- "No" --> NextFrame
  SaveHistory --> NextFrame
  NextFrame --> FrameLoop
```

## 4. Decision Engine Mapping

```mermaid
flowchart LR
  SpineDeviation["spineDeviation or spineAngleDeg"]
  LateralDeviation["lateralDeviation or lateralLeanDeg"]
  SpineVelocity["velocitySpine"]
  Mode["Mode scale"]
  Confidence["confidence"]

  Gate{"confidence < 0.65?"}
  Prev["Return previous positions"]
  ForwardMap["Forward proportional map"]
  VelocityBonus["Velocity anticipation bonus"]
  LateralSplit["Lateral opposite-column boost"]
  Scale["Apply mode scale"]
  Clamp["Clamp each value 0-55"]
  Hysteresis["Only change if delta >= 3"]
  Positions["[UL, UR, ML, MR, LL, LR] positions"]

  Confidence --> Gate
  Gate -- "Yes" --> Prev
  Prev --> Positions
  Gate -- "No" --> ForwardMap
  SpineDeviation --> ForwardMap
  SpineVelocity --> VelocityBonus
  VelocityBonus --> ForwardMap
  LateralDeviation --> LateralSplit
  ForwardMap --> Scale
  LateralSplit --> Scale
  Mode --> Scale
  Scale --> Clamp
  Clamp --> Hysteresis
  Hysteresis --> Positions
```

## 5. BLE Packet Path

```mermaid
sequenceDiagram
  participant App as Browser App
  participant BLE as Web Bluetooth
  participant ESP as ESP32 DevKit NimBLE
  participant FW as Firmware Parser
  participant MC as MotorController
  participant UI as Dashboard UI

  App->>App: Clamp positions to 0-55
  App->>App: Build 8-byte packet
  Note over App: A5 UL UR ML MR LL LR XOR
  App->>BLE: writeValueWithoutResponse(command)
  BLE->>ESP: Command characteristic write
  ESP->>FW: onWrite callback
  FW->>FW: Validate length, header, checksum
  alt Valid packet
    FW->>MC: setTarget(i, position)
    FW->>FW: lastValidPacketMs = millis()
  else Invalid packet
    FW-->>ESP: Drop packet
  end
  ESP->>ESP: Every 1000ms build status
  Note over ESP: 5A flags battery_mV UL UR ML MR LL LR
  ESP->>BLE: notify(status)
  BLE->>App: characteristicvaluechanged
  App->>UI: Update homed, moving, failsafe, estimated positions
```

## 6. ESP32 Firmware Loop

```mermaid
flowchart TD
  Boot["Power-on / reset"]
  InitSerial["Start Serial"]
  InitMotorPins["Attach RPWM and LPWM PWM pins"]
  EnableDrivers["Set shared EN_PIN HIGH"]
  HomeAll["Run all motors inward for HOMING_TIMEOUT_MS"]
  ZeroPositions["Set open-loop position estimates to 0"]
  StartBLE["Advertise as POSCHAIR_001"]
  Loop["Main loop"]
  UpdateMotors["MotorController.update"]
  Timeout{"No valid BLE packet > 2000ms?"}
  EnterFailsafe["Set failsafe active"]
  RetractAll["Command all targets to 0mm"]
  StatusDue{"Status interval elapsed?"}
  Notify["Notify 10-byte status packet"]
  Continue["Continue loop"]

  Boot --> InitSerial
  InitSerial --> InitMotorPins
  InitMotorPins --> EnableDrivers
  EnableDrivers --> HomeAll
  HomeAll --> ZeroPositions
  ZeroPositions --> StartBLE
  StartBLE --> Loop
  Loop --> UpdateMotors
  UpdateMotors --> Timeout
  Timeout -- "Yes" --> EnterFailsafe
  EnterFailsafe --> RetractAll
  RetractAll --> StatusDue
  Timeout -- "No" --> StatusDue
  StatusDue -- "Yes" --> Notify
  StatusDue -- "No" --> Continue
  Notify --> Continue
  Continue --> Loop
```

## 7. Single Module Motor Control

```mermaid
stateDiagram-v2
  [*] --> IDLE
  IDLE --> MOVING_OUT: target > current
  IDLE --> MOVING_IN: target < current
  MOVING_OUT --> IDLE: run duration elapsed
  MOVING_IN --> IDLE: run duration elapsed
  IDLE --> HOMING: startup
  HOMING --> IDLE: timeout complete and position zeroed
  MOVING_OUT --> MOVING_IN: new lower target
  MOVING_IN --> MOVING_OUT: new higher target
  MOVING_OUT --> IDLE: stopAll
  MOVING_IN --> IDLE: stopAll
```

```mermaid
flowchart LR
  Target["Target position 0-55mm"]
  Current["Open-loop estimated position"]
  Delta["delta_mm = abs(target - current)"]
  Speed["MOTOR_SPEED_MM_PER_MS"]
  Duration["duration_ms = delta_mm / speed"]
  Direction{"target > current?"}
  Out["Extend: RPWM=200 LPWM=0"]
  In["Retract: RPWM=0 LPWM=200"]
  Stop["Stop: RPWM=0 LPWM=0"]
  Update["Continuously update open-loop estimate"]

  Target --> Delta
  Current --> Delta
  Delta --> Duration
  Speed --> Duration
  Duration --> Direction
  Direction -- "Yes" --> Out
  Direction -- "No" --> In
  Out --> Stop
  In --> Stop
  Stop --> Update
```

## 8. Physical Output Grid

```mermaid
flowchart TB
  subgraph Grid["2x3 Paraspinal Actuator Grid"]
    UL["M0 UL: Upper-Left foam pad"]
    UR["M1 UR: Upper-Right foam pad"]
    ML["M2 ML: Mid-Left foam pad"]
    MR["M3 MR: Mid-Right foam pad"]
    LL["M4 LL: Lower-Left foam pad"]
    LR["M5 LR: Lower-Right foam pad"]
  end

  subgraph Anatomy["User Back Contact Zones"]
    ULeft["Upper-left paraspinal zone"]
    URight["Upper-right paraspinal zone"]
    MLeft["Mid-left lumbar zone"]
    MRight["Mid-right lumbar zone"]
    LLeft["Lower-left pelvis/lumbar zone"]
    LRight["Lower-right pelvis/lumbar zone"]
    SpineGap["2cm open spine gap"]
  end

  UL --> ULeft
  UR --> URight
  ML --> MLeft
  MR --> MRight
  LL --> LLeft
  LR --> LRight
  ULeft --- SpineGap
  MLeft --- SpineGap
  LLeft --- SpineGap
  SpineGap --- URight
  SpineGap --- MRight
  SpineGap --- LRight
```

## 9. Safety and Failure Paths

```mermaid
flowchart TD
  Normal["Normal vision-guided operation"]
  BadPacket["Bad BLE packet"]
  LowConfidence["Low pose confidence"]
  BLETimeout["No valid BLE command for 2s"]
  PowerCycle["Power cycle / reset"]
  ManualStop["User stops camera or disconnects"]

  Drop["Drop packet, keep previous target"]
  Hold["Hold previous positions"]
  Retract["Retract all modules to 0mm"]
  Home["Startup homing to 0mm"]
  UIWarn["Show UI warning or disconnected state"]
  Fallback["Software fallback state (not safety-rated)"]

  Normal --> BadPacket
  Normal --> LowConfidence
  Normal --> BLETimeout
  Normal --> PowerCycle
  Normal --> ManualStop

  BadPacket --> Drop
  Drop --> BLETimeout
  LowConfidence --> Hold
  Hold --> BLETimeout
  BLETimeout --> Retract
  Retract --> Fallback
  PowerCycle --> Home
  Home --> Fallback
  ManualStop --> UIWarn
  UIWarn --> BLETimeout
```

## 10. Backend Data Flow

```mermaid
flowchart LR
  UI["React dashboard"]
  Profile["Profile form / default user"]
  CalibrationModal["Calibration modal"]
  Session["Monitoring session"]
  API["FastAPI backend"]
  DB["PostgreSQL"]
  Analytics["Analytics dashboard"]

  Profile --> UI
  CalibrationModal --> UI
  Session --> UI
  UI -->|POST /profile| API
  UI -->|POST /calibration| API
  UI -->|POST /sessions| API
  UI -->|GET /sessions/:userId| API
  API --> DB
  DB --> API
  API --> Analytics
  Analytics --> UI
```

## 11. Key Signals and Units

| Signal | Source | Destination | Unit / Format |
|---|---|---|---|
| Camera frames | Browser camera | MediaPipe Pose | Video frame |
| Pose landmarks | MediaPipe Pose | Posture analyzer | 33 landmarks |
| `spineAngleDeg` | Posture analyzer | Decision engine / UI | Degrees |
| `lateralLeanDeg` | Posture analyzer | Decision engine / UI | Degrees |
| `velocitySpine` | Posture analyzer | Decision engine / UI | Degrees per second |
| `confidence` | Pose landmarks | Decision engine / UI | 0.0-1.0 |
| Target positions | Decision engine | BLE manager | 6 values, 0-55mm |
| Command packet | BLE manager | ESP32 DevKit V1 | 8 bytes |
| Battery voltage | ESP32 DevKit V1 ADC | Dashboard status packet | Millivolts |
| Estimated positions | ESP32 DevKit V1 | Dashboard UI | 6 values, 0-55mm, open-loop |
| Motor PWM | ESP32 DevKit V1 | BTS7960 drivers | 0-255 duty |
| Foam pad travel | Worm-rack actuator | User back | 0-55mm configured limit |

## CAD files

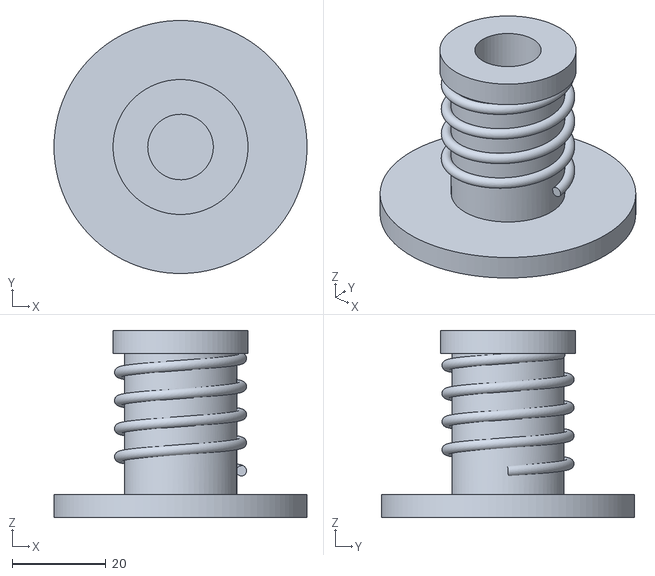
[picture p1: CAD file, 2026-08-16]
new actuator (tube actuator)/InnerTube.stl
54.0 x 54.0 x 40.0

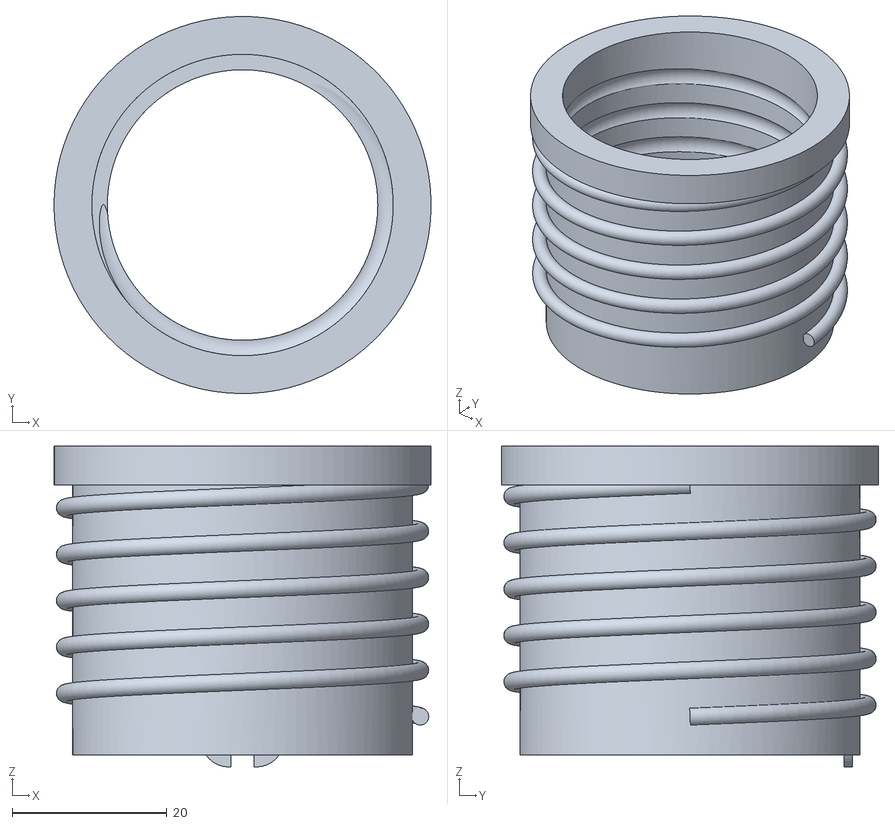
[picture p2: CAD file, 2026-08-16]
new actuator (tube actuator)/Middle2Tube.stl
48.8 x 48.8 x 41.5

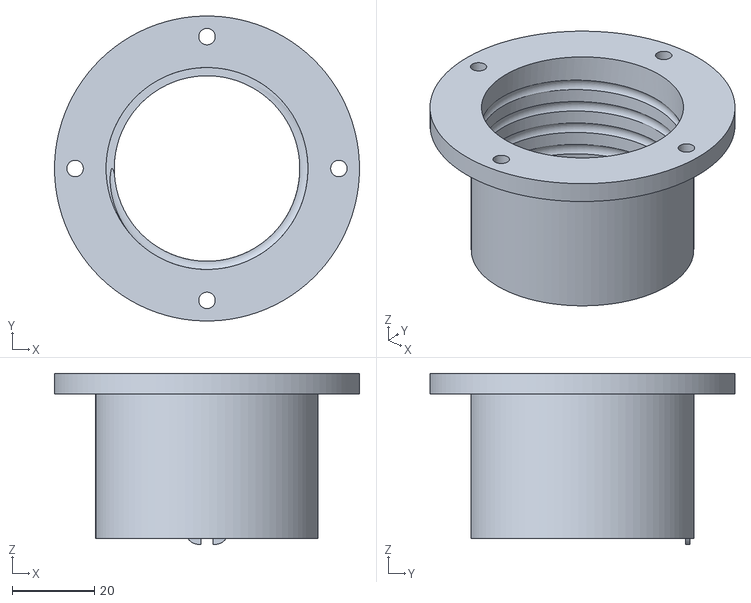
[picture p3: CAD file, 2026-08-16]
new actuator (tube actuator)/OuterTube.stl
74.0 x 74.0 x 41.5

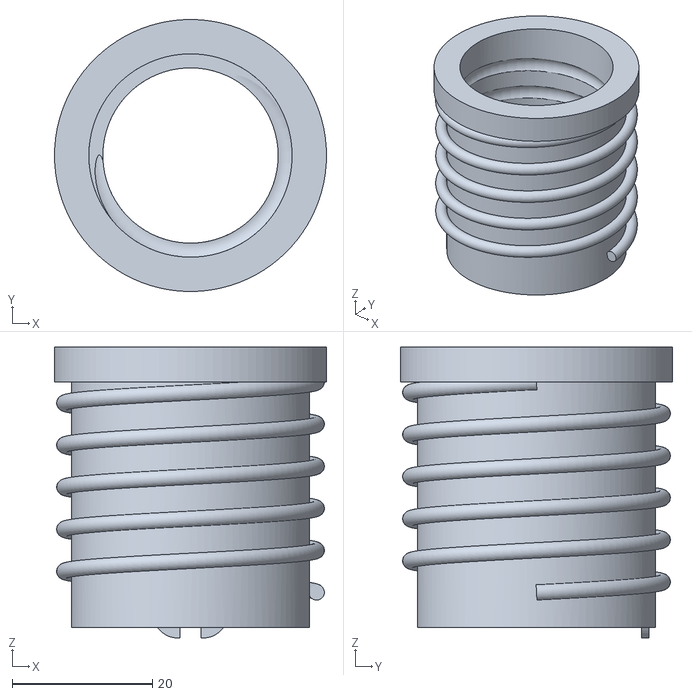
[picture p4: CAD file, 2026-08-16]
new actuator (tube actuator)/Middle1Tube.stl
38.8 x 38.8 x 41.5

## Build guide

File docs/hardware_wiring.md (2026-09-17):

# PosChair V3 Build Wiring Guide

This is the build-facing wiring reference for the ESP32 DevKit V1 version of PosChair V3. Follow this when connecting the ESP32, six BTS7960 motor drivers, six DC geared motors, the 12V motor supply, and the battery voltage divider.

## Read This First

- Do not power motors from the ESP32, USB, or breadboard power rails.
- Use a separate motor supply sized for the stall current of all six motors.
- All grounds must be common: ESP32 GND, BTS7960 GND, motor battery negative, and voltage-divider ground.
- Avoid ESP32 GPIO0, GPIO2, GPIO12, and GPIO15 for motors because they are boot-strapping pins.
- Avoid GPIO6-GPIO11 because they are connected to onboard flash.
- Wire and test one motor module first before connecting all six.

## Parts In This Wiring

| Item | Qty | Notes |
|---|---:|---|
| ESP32 DevKit V1, 38-pin | 1 | Arduino board target: `ESP32 Dev Module` |
| BTS7960 H-bridge driver | 6 | One driver per actuator |
| DC geared motor | 6 | One motor per worm-rack actuator |
| Worm-rack actuator + foam pad | 6 | 0-55mm configured travel limit |
| 12V motor battery / supply | 1 | Motor power rail only |
| 120k resistor | 1 | Battery voltage-divider high side |
| 27k resistor | 1 | Battery voltage-divider low side |
| 100nF ceramic capacitor | 1 | ADC filtering, from GPIO34 to ground |
| Common ground bus | 1 | Required |
| Inline fuse / switch | 1 required | Put on battery positive |
| Latching emergency-stop switch | 1 required for occupied testing | Interrupt the motor supply |

## Physical Grid

```text
        LEFT COLUMN      RIGHT COLUMN

ROW 1:  [M0 UL]         [M1 UR]       Upper thoracic / shoulder
ROW 2:  [M2 ML]         [M3 MR]       Mid lumbar
ROW 3:  [M4 LL]         [M5 LR]       Lower lumbar / pelvis
```

Keep a 2cm open gap between left and right columns. The foam pads should contact paraspinal muscles, not the spine itself.

## Full Connection Map

Label your BTS7960 boards `M0` through `M5` before wiring.

| Module | Body Position | BTS7960 RPWM | BTS7960 LPWM | BTS7960 R_EN | BTS7960 L_EN | Motor Output |
|---|---|---:|---:|---:|---:|---|
| M0 | Upper-Left | ESP32 GPIO25 | ESP32 GPIO26 | ESP32 GPIO5 | ESP32 GPIO5 | M0 motor `M+` / `M-` |
| M1 | Upper-Right | ESP32 GPIO27 | ESP32 GPIO16 | ESP32 GPIO5 | ESP32 GPIO5 | M1 motor `M+` / `M-` |
| M2 | Mid-Left | ESP32 GPIO14 | ESP32 GPIO13 | ESP32 GPIO5 | ESP32 GPIO5 | M2 motor `M+` / `M-` |
| M3 | Mid-Right | ESP32 GPIO17 | ESP32 GPIO18 | ESP32 GPIO5 | ESP32 GPIO5 | M3 motor `M+` / `M-` |
| M4 | Lower-Left | ESP32 GPIO21 | ESP32 GPIO22 | ESP32 GPIO5 | ESP32 GPIO5 | M4 motor `M+` / `M-` |
| M5 | Lower-Right | ESP32 GPIO23 | ESP32 GPIO19 | ESP32 GPIO5 | ESP32 GPIO5 | M5 motor `M+` / `M-` |

## ESP32 Pin Checklist

| ESP32 Pin | Connect To | Purpose |
|---:|---|---|
| GPIO25 | M0 BTS7960 `RPWM` | Upper-left extend PWM |
| GPIO26 | M0 BTS7960 `LPWM` | Upper-left retract PWM |
| GPIO27 | M1 BTS7960 `RPWM` | Upper-right extend PWM |
| GPIO16 | M1 BTS7960 `LPWM` | Upper-right retract PWM |
| GPIO14 | M2 BTS7960 `RPWM` | Mid-left extend PWM |
| GPIO13 | M2 BTS7960 `LPWM` | Mid-left retract PWM |
| GPIO17 | M3 BTS7960 `RPWM` | Mid-right extend PWM |
| GPIO18 | M3 BTS7960 `LPWM` | Mid-right retract PWM |
| GPIO21 | M4 BTS7960 `RPWM` | Lower-left extend PWM |
| GPIO22 | M4 BTS7960 `LPWM` | Lower-left retract PWM |
| GPIO23 | M5 BTS7960 `RPWM` | Lower-right extend PWM |
| GPIO19 | M5 BTS7960 `LPWM` | Lower-right retract PWM |
| GPIO5 | All BTS7960 `R_EN` and `L_EN` | Shared driver enable |
| GPIO34 | Voltage divider midpoint | Battery voltage ADC |
| 3.3V | All BTS7960 `VCC` pins | Logic power |
| GND | Ground bus | Common logic and motor reference |

## BTS7960 Pin Checklist

Repeat this for each of the six BTS7960 boards.

| BTS7960 Pin | Connect To | Notes |
|---|---|---|
| `RPWM` | Assigned ESP32 RPWM GPIO | Motor extends foam pad when active |
| `LPWM` | Assigned ESP32 LPWM GPIO | Motor retracts foam pad when active |
| `R_EN` | ESP32 GPIO5 | Shared enable |
| `L_EN` | ESP32 GPIO5 | Shared enable |
| `VCC` | ESP32 3.3V | Logic only |
| `GND` | Common ground bus | Must share ESP32 and battery ground |
| `B+` | 12V motor supply positive | Put fuse/switch before distribution |
| `B-` | 12V motor supply negative | Same as common ground |
| `M+` | Motor terminal 1 | Swap with `M-` if direction is reversed |
| `M-` | Motor terminal 2 | Swap with `M+` if direction is reversed |

## Motor Direction Rule

Firmware assumes:

```text
RPWM active, LPWM 0  -> actuator extends, foam pushes out
LPWM active, RPWM 0  -> actuator retracts, foam pulls in
```

If a module moves the wrong way during `poschair_motor_test.ino`, do not change code first. Swap that module motor's `M+` and `M-` wires on the BTS7960 output.

## Power Wiring

```text
12V supply positive -> fuse/switch -> split to all BTS7960 B+ terminals
12V supply negative -> ground bus -> all BTS7960 B- terminals
ESP32 GND -----------> same ground bus
All BTS7960 GND -----> same ground bus
ESP32 3.3V ----------> all BTS7960 VCC logic pins
```

Use thicker wire for `B+`, `B-`, `M+`, and `M-` than for ESP32 signal wires.

## Battery Voltage Divider

Do not use an equal-value divider on a 12V rail. It would place roughly 6V
on GPIO34 and can damage the ESP32. The reference divider
below keeps the ADC under 2.76V even if the supply reaches 15V.

```text
Battery + ---- R1 120k ----+---- ESP32 GPIO34
                           |          |
                           R2 27k     C1 100nF
                           |          |
Ground bus ----------------+----------+
```

Firmware constants:

```cpp
#define BATTERY_ADC_PIN 34
#define BATTERY_R1_OHMS 120000.0f
#define BATTERY_R2_OHMS 27000.0f
#define BATTERY_DIVIDER_RATIO ((BATTERY_R1_OHMS + BATTERY_R2_OHMS) / BATTERY_R2_OHMS)
```

Measure the actual battery voltage with a calibrated multimeter and tune
`BATTERY_CALIBRATION_FACTOR` before relying on dashboard readings.

## Human-Use Hardware Gate

The current timed-position controller is suitable for an unoccupied bench
prototype only. Do not test the powered actuator matrix against a person until
all of the following have been implemented and independently verified:

1. A normally-closed, latching emergency stop that removes motor power.
2. Independent retract and extend limit sensing for every actuator.
3. Motor-current or load/force monitoring with a hardware cutoff.
4. Mechanical end stops that survive the worst-case motor stall load.
5. Per-channel fusing or current limiting sized from measured stall current.
6. A verified maximum pad force and pressure for every supported body position.
7. A fault test covering a disconnected sensor, jammed actuator, BLE loss, and controller reset.

Software timeout retraction is not a substitute for these hardware controls.

## Build Order

1. Mount the six actuator modules on the chair frame.
2. Label each motor wire pair as `M0` through `M5`.
3. Label each BTS7960 board as `M0` through `M5`.
4. Wire only the M0 driver and motor first.
5. Connect ESP32 GND to the motor supply ground.
6. Connect M0 `RPWM`, `LPWM`, `R_EN`, `L_EN`, `VCC`, and `GND`.
7. Connect M0 `B+`, `B-`, `M+`, and `M-`.
8. Flash `firmware/poschair_motor_test/poschair_motor_test.ino`.
9. Confirm M0 extends during OUT and retracts during IN.
10. If M0 direction is wrong, swap M0 `M+` and `M-`.
11. Repeat the same process for M1 through M5.
12. After all six pass the motor test, flash `firmware/poschair_firmware/poschair_firmware.ino`.

## First Power-Up Test

Use this sequence before wearing or leaning against the chair:

1. Keep motors disconnected from the user's back.
2. Power ESP32 from USB only.
3. Open Serial Monitor at `115200`.
4. Confirm boot message prints.
5. Power the 12V motor rail.
6. Run the motor test sketch.
7. Confirm every module extends and retracts in the correct physical location.
8. Measure 2000ms travel for each actuator.
9. Calculate `MOTOR_SPEED_MM_PER_MS = measured_mm / 2000.0`.
10. Update `firmware/poschair_firmware/config.h`.
11. Flash the main firmware.
12. Confirm startup homing retracts all modules.

## Arduino IDE Target

- Board: `ESP32 Dev Module`
- CPU Frequency: `240MHz`
- Upload Speed: `921600`
- Flash Size: `4MB`
- Partition Scheme: `Default 4MB with spiffs`
- USB CDC On Boot: not applicable on DevKit V1

If upload fails, hold the BOOT button while starting upload and release it after `Connecting...` appears.

## Quick Troubleshooting

| Symptom | Likely Cause | Fix |
|---|---|---|
| ESP32 resets when motors move | Motor power sag or shared weak supply | Use stronger 12V supply and common ground |
| Motor does not move | EN not HIGH, no motor power, wrong driver pin | Check GPIO5 to R_EN/L_EN and B+/B- |
| Motor moves backward | Motor output polarity reversed | Swap `M+` and `M-` on that driver |
| Only one direction works | RPWM/LPWM swapped or loose wire | Recheck assigned GPIO and BTS7960 pin |
| BLE works but motors do nothing | Driver enable/power missing | Check GPIO5, VCC, GND, B+ and B- |
| Battery reading is wrong | Divider ratio, ADC calibration, or ground wrong | Verify 120k/27k values, common ground, and calibration factor |
| Upload fails | DevKit boot mode issue | Hold BOOT until upload starts |

## Final Safety Check

- All `B-` and ESP32 `GND` points share a common ground.
- No motor current flows through the ESP32 board.
- Every motor can retract before testing extension.
- Foam pads have soft edges and mechanical travel limits.
- The first full test is done without a person leaning on the chair.
- The motor rail has a tested latching emergency stop.
- Occupied testing remains disabled until the human-use hardware gate is complete.

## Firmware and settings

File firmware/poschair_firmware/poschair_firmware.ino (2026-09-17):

// PosChair Firmware v3 - ESP32 DevKit V1
// 6 custom worm-rack actuators in 2x3 paraspinal grid.
// Drivers: 6x BTS7960 H-bridges, one DC geared motor per module.
//
// Board: ESP32 Dev Module
// CPU Frequency: 240MHz
// Library: NimBLE-Arduino

#include "config.h"
#include "protocol.h"
#include "motor_controller.h"
#include "ble_manager.h"

MotorController motors;
unsigned long lastStatusMs = 0;
bool failsafeActive = false;

uint16_t readBatteryMv() {
  const uint32_t adcMv = analogReadMilliVolts(BATTERY_ADC_PIN);
  const float inputMv = adcMv * BATTERY_DIVIDER_RATIO * BATTERY_CALIBRATION_FACTOR;
  return (uint16_t)min(inputMv, 65535.0f);
}

void setup() {
  Serial.begin(115200);
  delay(200);
  Serial.println("\n=== PosChair v3 Firmware Starting ===");
  Serial.println("Layout: UL=M0 UR=M1 ML=M2 MR=M3 LL=M4 LR=M5");
  Serial.println("Actuator: BTS7960 + DC motor + worm-rack timed position control");

  analogSetPinAttenuation(BATTERY_ADC_PIN, ADC_11db);

  motors.begin();
  motors.homeAll();
  bleManager.begin(&motors);

  Serial.printf("Ready. Positions are 0-%dmm. Advertising as %s.\n", MAX_POSITION_MM, BLE_DEVICE_NAME);
}

void loop() {
  motors.update();

  const bool timedOut = (millis() - bleManager.lastValidPacketMs() > FAILSAFE_TIMEOUT_MS);
  if (timedOut && !failsafeActive) {
    Serial.println("WARNING: BLE timeout - retracting all modules to 0mm");
    failsafeActive = true;
    for (int i = 0; i < NUM_MODULES; i++) motors.setTarget(i, 0);
  }
  if (!timedOut) failsafeActive = false;

  if (millis() - lastStatusMs > STATUS_INTERVAL_MS) {
    lastStatusMs = millis();
    const uint16_t batteryMv = readBatteryMv();
    bleManager.sendStatus(failsafeActive, batteryMv);

    Serial.printf("[Status] UL=%d UR=%d ML=%d MR=%d LL=%d LR=%d bat=%dmV homed=%d moving=%d fs=%d\n",
      motors.getCurrentPosition(0), motors.getCurrentPosition(1),
      motors.getCurrentPosition(2), motors.getCurrentPosition(3),
      motors.getCurrentPosition(4), motors.getCurrentPosition(5),
      batteryMv, motors.isHomingComplete(), motors.isAnyMoving(), failsafeActive);
  }
}

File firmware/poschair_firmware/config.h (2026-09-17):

#pragma once
#include <Arduino.h>

// Module index map:
// 0=Upper-Left, 1=Upper-Right, 2=Mid-Left, 3=Mid-Right, 4=Lower-Left, 5=Lower-Right
#define NUM_MODULES 6

// BTS7960 PWM pin assignments for ESP32 DevKit V1 (38-pin).
// Avoid GPIO0, GPIO2, GPIO12, and GPIO15 because they are boot-strapping pins.
// Avoid GPIO6-GPIO11 because they are connected to the onboard flash chip.
// RPWM drives rack out, LPWM drives rack in.
const uint8_t RPWM_PINS[NUM_MODULES] = {25, 27, 14, 17, 21, 23};
const uint8_t LPWM_PINS[NUM_MODULES] = {26, 16, 13, 18, 22, 19};

// Shared enable pin. Tie all BTS7960 R_EN and L_EN pins here, HIGH = enabled.
#define EN_PIN 5

// Battery voltage divider input. GPIO34 is input-only and ADC1_CH6.
// Wiring: Battery+ -> R1 120k -> GPIO34 -> R2 27k -> GND.
// This keeps the ADC below 2.76V at a 15V worst-case supply input.
#define BATTERY_ADC_PIN 34
#define BATTERY_R1_OHMS 120000.0f
#define BATTERY_R2_OHMS 27000.0f
#define BATTERY_DIVIDER_RATIO ((BATTERY_R1_OHMS + BATTERY_R2_OHMS) / BATTERY_R2_OHMS)
#define BATTERY_CALIBRATION_FACTOR 1.0f
#define BATTERY_MAX_INPUT_MV 15000

// Motor PWM settings for ESP32 Arduino core v3 ledcAttach/ledcWrite API.
#define MOTOR_PWM_NORMAL 200
#define MOTOR_PWM_HOMING 150
#define MOTOR_PWM_FREQ 5000
#define MOTOR_PWM_RES 8

// Timed position model: position unit 0-55 maps to 0-55mm extension.
// 55mm is the current prototype's configured mechanical travel limit.
#define MOTOR_SPEED_MM_PER_MS 0.075f
#define MAX_POSITION_MM 55
#define POSITION_UNIT_TO_MM 1.0f

// Homing and safety.
#define HOMING_TIMEOUT_MS 3000
#define HOMING_EXTRA_MS 200
#define FAILSAFE_TIMEOUT_MS 2000
#define MIN_POSITION_CHANGE 3

// BLE UUIDs. Must match app/frontend/src/bleManager.ts exactly.
#define BLE_DEVICE_NAME "POSCHAIR_001"
#define SERVICE_UUID "a1b2c3d4-0001-4b5c-8d6e-1f2a3b4c5d6e"
#define COMMAND_CHAR_UUID "a1b2c3d4-0002-4b5c-8d6e-1f2a3b4c5d6e"
#define STATUS_CHAR_UUID "a1b2c3d4-0003-4b5c-8d6e-1f2a3b4c5d6e"

#define STATUS_INTERVAL_MS 1000

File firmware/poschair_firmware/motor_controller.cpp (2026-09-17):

#include "motor_controller.h"

void MotorController::begin() {
  pinMode(EN_PIN, OUTPUT);
  digitalWrite(EN_PIN, HIGH);

  for (int i = 0; i < NUM_MODULES; i++) {
    ledcAttach(RPWM_PINS[i], MOTOR_PWM_FREQ, MOTOR_PWM_RES);
    ledcAttach(LPWM_PINS[i], MOTOR_PWM_FREQ, MOTOR_PWM_RES);
    _stop(i);
    _estimatedPos[i] = 0.0f;
    _moveStartPos[i] = 0.0f;
    _targetPos[i] = 0;
    _state[i] = MotorState::IDLE;
  }

  Serial.println("[Motor] BTS7960 outputs initialised.");
}

void MotorController::homeAll() {
  Serial.println("[Motor] Homing all modules to fully retracted position...");
  _homingDone = false;

  for (int i = 0; i < NUM_MODULES; i++) {
    _state[i] = MotorState::HOMING;
    _driveIn(i, MOTOR_PWM_HOMING);
  }

  delay(HOMING_TIMEOUT_MS);

  for (int i = 0; i < NUM_MODULES; i++) {
    _brake(i);
  }
  delay(HOMING_EXTRA_MS);

  for (int i = 0; i < NUM_MODULES; i++) {
    _stop(i);
    _estimatedPos[i] = 0.0f;
    _moveStartPos[i] = 0.0f;
    _targetPos[i] = 0;
    _state[i] = MotorState::IDLE;
  }

  _homingDone = true;
  Serial.println("[Motor] Homing complete. All positions zeroed.");
}

void MotorController::setTarget(int idx, uint8_t position) {
  if (idx < 0 || idx >= NUM_MODULES) return;
  if (position > MAX_POSITION_MM) position = MAX_POSITION_MM;

  if (abs((int)position - (int)_targetPos[idx]) < MIN_POSITION_CHANGE) return;

  const unsigned long now = millis();
  _updateEstimatedPosition(idx, now);
  _targetPos[idx] = position;
  _moveStartPos[idx] = _estimatedPos[idx];
  _moveDurationMs[idx] = _durationForDelta(_moveStartPos[idx], _targetPos[idx]);
  _moveStartMs[idx] = now;

  if (_moveDurationMs[idx] == 0 || abs(_estimatedPos[idx] - _targetPos[idx]) < 0.5f) {
    _stop(idx);
    _estimatedPos[idx] = _targetPos[idx];
    _state[idx] = MotorState::IDLE;
    return;
  }

  if (_targetPos[idx] > _estimatedPos[idx]) {
    _state[idx] = MotorState::MOVING_OUT;
    _driveOut(idx, MOTOR_PWM_NORMAL);
  } else {
    _state[idx] = MotorState::MOVING_IN;
    _driveIn(idx, MOTOR_PWM_NORMAL);
  }
}

void MotorController::update() {
  const unsigned long now = millis();

  for (int i = 0; i < NUM_MODULES; i++) {
    if (_state[i] != MotorState::MOVING_OUT && _state[i] != MotorState::MOVING_IN) continue;

    _updateEstimatedPosition(i, now);
    const unsigned long elapsed = now - _moveStartMs[i];
    if (elapsed >= _moveDurationMs[i]) {
      _stop(i);
      _estimatedPos[i] = _targetPos[i];
      _state[i] = MotorState::IDLE;
    }
  }
}

uint8_t MotorController::getCurrentPosition(int idx) const {
  if (idx < 0 || idx >= NUM_MODULES) return 0;
  return (uint8_t)constrain((int)roundf(_estimatedPos[idx]), 0, MAX_POSITION_MM);
}

bool MotorController::isAnyMoving() const {
  for (int i = 0; i < NUM_MODULES; i++) {
    if (_state[i] != MotorState::IDLE) return true;
  }
  return false;
}

void MotorController::stopAll() {
  const unsigned long now = millis();
  for (int i = 0; i < NUM_MODULES; i++) {
    _updateEstimatedPosition(i, now);
    _stop(i);
    _targetPos[i] = getCurrentPosition(i);
    _state[i] = MotorState::IDLE;
  }
}

void MotorController::_driveOut(int idx, uint8_t pwm) {
  ledcWrite(RPWM_PINS[idx], pwm);
  ledcWrite(LPWM_PINS[idx], 0);
}

void MotorController::_driveIn(int idx, uint8_t pwm) {
  ledcWrite(RPWM_PINS[idx], 0);
  ledcWrite(LPWM_PINS[idx], pwm);
}

void MotorController::_stop(int idx) {
  ledcWrite(RPWM_PINS[idx], 0);
  ledcWrite(LPWM_PINS[idx], 0);
}

void MotorController::_brake(int idx) {
  ledcWrite(RPWM_PINS[idx], 255);
  ledcWrite(LPWM_PINS[idx], 255);
}

void MotorController::_updateEstimatedPosition(int idx, unsigned long now) {
  if (_state[idx] != MotorState::MOVING_OUT && _state[idx] != MotorState::MOVING_IN) return;
  if (_moveDurationMs[idx] == 0) {
    _estimatedPos[idx] = _targetPos[idx];
    return;
  }

  const unsigned long elapsed = now - _moveStartMs[idx];
  const float progress = min(1.0f, elapsed / (float)_moveDurationMs[idx]);
  _estimatedPos[idx] = _moveStartPos[idx]
    + (_targetPos[idx] - _moveStartPos[idx]) * progress;
}

unsigned long MotorController::_durationForDelta(float fromPos, uint8_t toPos) const {
  const float deltaMm = fabsf(toPos - fromPos) * POSITION_UNIT_TO_MM;
  if (MOTOR_SPEED_MM_PER_MS <= 0.0f) return 0;
  return (unsigned long)(deltaMm / MOTOR_SPEED_MM_PER_MS);
}

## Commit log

2026-08-16 fix: complete audit response — 10 critical bugs + 10 UI fixes
    CRITICAL BUGS FIXED:
    - poseDetector.ts: pin CDN to @0.10.14 (no more @latest drift), add
    DetectorState type + error field, propagate init errors to CameraView
    - CameraView.tsx: detectorReadyRef prevents loop racing init (Bug 2),
    loading overlay during model download, error overlay with user-friendly
    messages for NotAllowed/NotFound/model failure, await video.play() with
    autoplay-blocked handling (Bug 7)
    - backend/main.py: CORS origins now from CORS_ORIGINS env var, includes null
    for Electron, defaults to localhost:5173+3000+null (Bug 3)
    - backend/calibration.py: GET returns 404 instead of null-200 (Bug 4)
    - backend/pro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
    [InnerTube.stl, Middle1Tube.stl, Middle2Tube.stl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]
2026-08-16 feat: upgrade pose detection accuracy & skeleton visualization
    - poseDetector.ts: switch to pose_landmarker_full model for high precision; export DrawingUtils & PoseLandmarker
    - CameraView.tsx: render full 33-landmark skeleton with yellow keypoint dots (matching reference image); highlight spine alignment; mirrored video/canvas overlay; live metrics bar
    - postureAnalyzer.ts: EMA temporal smoothing (α=0.35); ear-shoulder neck inclination angle for FHP; scale-invariant torso & shoulder normalization; 3-component posture scoring
    - models.py & schemas.py & apiClient.ts & App.tsx & CalibrationModal.tsx: added neck_angle_0 & torso_length persistence
2026-08-16 feat: add Chair Hardware Motor State simulator overlay to camera view
    - CameraView.tsx: added ChairHardwareWidget overlay in top-right corner rendering the vibrant blue oval backrest with black border and 6 actuator circles (matching user diagram)
    - Actuator Node Logic: circles switch from bright YELLOW (resting/idle) to glowing RED (active extension/rotation) with pulsing aura and millimeter extension readout when motors move
    - App.tsx: passed targetPositions to CameraView to drive real-time hardware simulation during posture tracking in demo mode
2026-08-16 release: PosChair v1.3 — Full Pose Accuracy, Skeleton Overlay & Live Hardware Simulator
2026-08-16 style: overhaul marketing website design system with anti-slop technical aesthetics
    - globals.css: replaced generic clay-shadows with Dark Slate #08090d base, high-contrast crisp borders, Plus Jakarta Sans typography, JetBrains Mono code accents, and ambient radial glow
    - Hero.tsx: technical headline, interactive 2x3 Hardware Actuator Telemetry Simulator Console with live posture preset toggles (Normal, Slouch, Lean Right, Lean Left) driving real-time motor extension telemetry
    - HowItWorks.tsx: step-by-step pipeline breakdown with code snippet callouts (WASM Vision -> EMA Kinematics -> Matrix Mapping -> BLE & Motor Drivers)
    - Features.tsx: technical architecture cards with domain tags (Mecha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
2026-08-16 feat: add interactive hover documentation guide & dedicated /docs hub page
    - InteractiveDocs.tsx: 6-pillar system explorer card grid (Camera Vision, Pose Analyzer, Decision Engine, BLE Protocol, Hardware Grid, Safety Failsafe). Hovering over any component instantly shows a layman-friendly explanation with icons & technical spec callouts.
    - /docs page: dedicated documentation hub page featuring hardware wiring pinouts, BLE packet spec, and interactive system guide
    - Nav.tsx & index.tsx: linked Docs Guide in header navigation bar and rendered interactive documentation guide on homepage
2026-08-16 docs: expand README.md into beginner-friendly & technical manual + add run-poschair.bat launcher
    - README.md: added plain English 'What is PosChair?' summary, 60-second quick start guide for non-coders, double-click run-poschair.bat instructions, step-by-step UI guide, 2x3 paraspinal actuator pi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
    - run-poschair.bat: created 1-click Windows batch launcher for non-coders to run PosChair without terminal commands
2026-08-16 docs: overhaul README.md into encyclopedic master manual with math formulas, wiring tables, directory tree, and FAQ
